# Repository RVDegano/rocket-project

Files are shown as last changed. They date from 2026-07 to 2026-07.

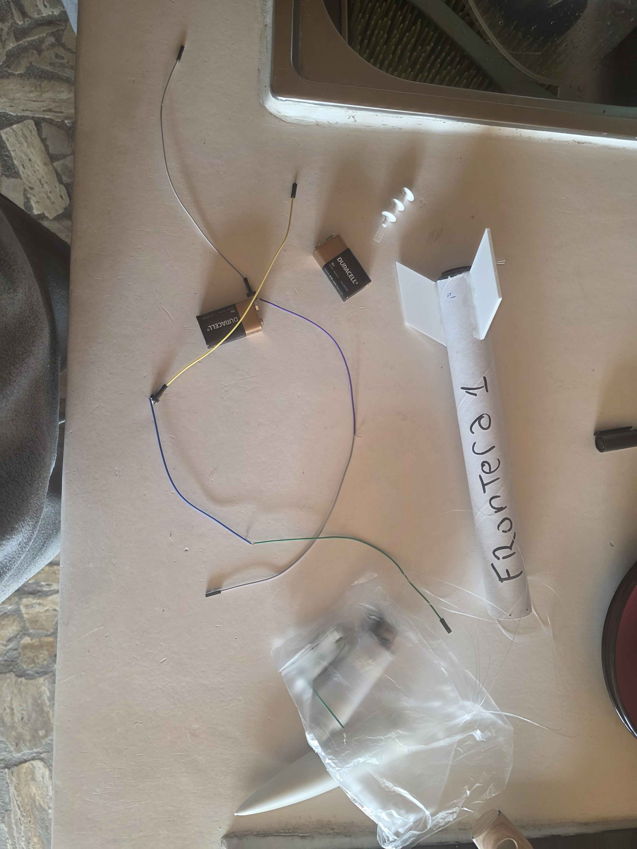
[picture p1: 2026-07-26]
DOCS/ARMADO FINAL.jpg

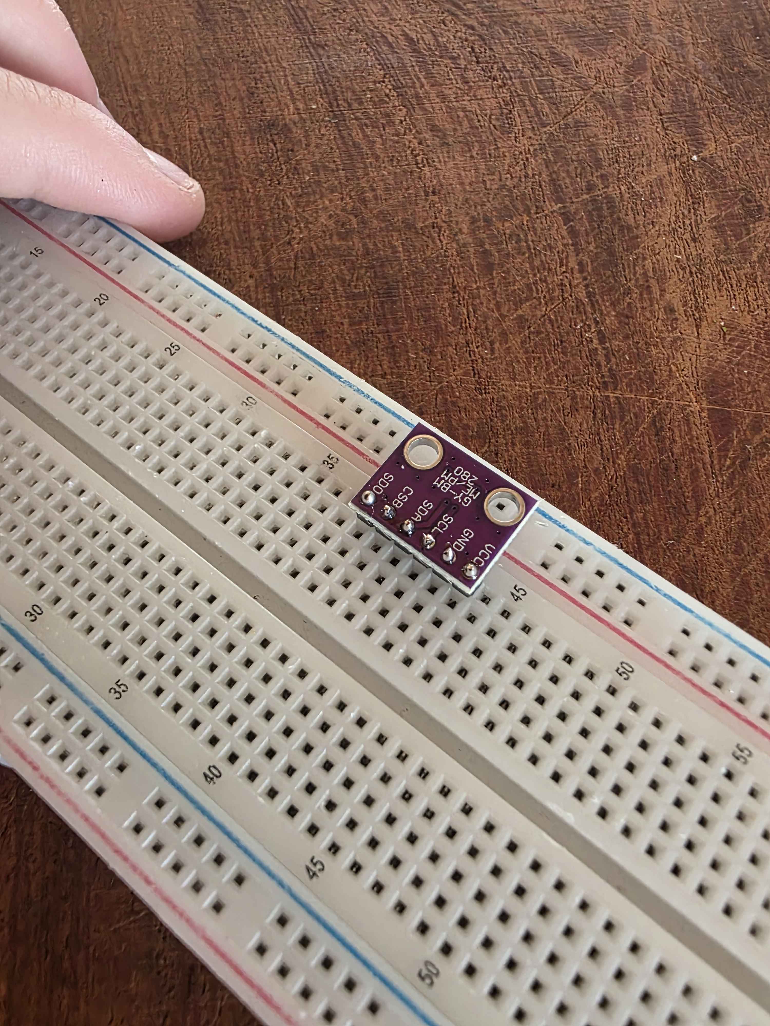
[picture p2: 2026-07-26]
DOCS/COMPONENTE.jpg

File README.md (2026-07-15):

# 🚀 Frontera 1 — D12-5 Flight Computer

A single-stage model rocket designed, simulated, and built from scratch. Includes a custom flight computer for onboard data logging during flight.

## 📋 Project Overview

| Parameter | Value |
|---|---|
| Motor | Estes D12-5 |
| Length | 42.5 cm |
| Max Diameter | 33 mm (body tube, external) |
| Mass (no motor) | 175 g |
| Mass (with motor) | 218 g |
| Stability Margin | 1.51 cal |

## 📊 Simulation Results (OpenRocket)

| Metric | Value |
|---|---|
| Apogee | 204 m |
| Max Velocity | 61.1 m/s (Mach 0.180) |
| Max Acceleration | 129 m/s² |
| CG | 24.2 cm |
| CP | 29.3 cm |

*Note: the design went through an earlier iteration with a heavier body tube that dropped stability to 1.15 cal and apogee to 180 m. This was corrected by adding a mass component near the nose, restoring the margin to 1.51 cal.*

## 🔧 Flight Computer

**Hardware:**
- Arduino Nano V3.0 (ATmega328)
- BMP280 — barometric altimeter (altitude + pressure + temperature)
- MPU6050 — IMU (acceleration + gyroscope, 6-axis)
- microSD module + card — onboard data storage

**Features:**
- Continuous data logging from power-on (20 Hz sampling rate)
- CSV output: timestamp, altitude, temperature, acceleration (x/y/z), gyroscope (x/y/z)
- No liftoff/apogee detection — logging starts as soon as the board is powered, before the rocket is loaded on the launch rail

**Recovery / ejection:**
Parachute deployment is **mechanical**, not electronically triggered. The D12-5 motor's built-in ejection charge (5-second delay after burnout) pushes the nose cone off by friction, releasing the parachute. The flight computer only logs data — it does not control ejection.

## 🖨️ Structure

| Component | Material |
|---|---|
| Body tube | Cardboard, 31.5 mm internal / 33 mm external diameter (0.75 mm wall) |
| Nose cone (ojiva) | PVC, 13 cm long, 1 mm wall |
| Fins | PETG, 3D printed, trapezoidal |

PETG was selected for the fins for its heat resistance near the motor mount / ejection charge area.

## 📁 Repository Structure

```
rocket-project/
├── simulation/        # OpenRocket files (.ork)
├── firmware/           # Arduino Nano code
├── cad/                 # 3D models (STL files, fins)
├── docs/                # Photos, flight data, analysis
└── README.md
```

## 🎯 Goals

- [x] OpenRocket simulation complete
- [x] Motor selection finalized (D12-5, chosen over Quest D16-4 for higher apogee — D16-4 reserved for a future test flight)
- [x] Flight computer designed
- [ ] Fins printed and assembled
- [ ] Full assembly
- [ ] Launch — school showcase, San Bonifacio, October 2026 (launch site: Finca Cinco Cumbres, Mendoza)
- [ ] Post-launch data analysis

## 📸 Build Process

Photos coming as construction progresses.

## 🛠️ Tools & Software

- OpenRocket — flight simulation
- Arduino IDE — firmware
- Tinkercad — 3D modeling (fins)

## 👤 Author

**Rocco V. Degano**
Electronics technician student — Instituto Tecnológico San Bonifacio, Lomas de Zamora
Interested in aerospace propulsion and flight systems.
Part of a personal aerospace engineering portfolio.

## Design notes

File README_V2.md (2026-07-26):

# 🚀 Frontera 1 — D12-5 Flight Computer

A single-stage model rocket designed, simulated, and built from scratch. Includes a custom flight computer for onboard data logging during flight. First launch completed successfully at Finca Cinco Cumbres, Uspallata, Mendoza (Argentina).

## 📋 Project Overview

| Parameter | Value |
|---|---|
| Motor | Estes D12-5 |
| Length | 42.5 cm |
| Max Diameter | 33 mm (body tube, external) |
| Mass (no motor) | 175 g |
| Mass (with motor) | 218 g |
| Stability Margin | 1.51 cal |

## 📊 Simulation vs. Real Flight Data

| Metric | Simulated (OpenRocket) | Real (first launch) |
|---|---|---|
| Apogee | 204 m | **178 m** |
| Max Acceleration | ~129 m/s² (sim, peak) | **61 m/s²** (measured) |
| Max Velocity | 61.1 m/s | — |
| Flight Duration | ~30-40 s (estimated) | **50 s** |
| Temperature | — | 11°C |

The real apogee came in below simulation, which is expected — real-world drag, wind, and the exact mass with all electronics loaded are hard to match perfectly in simulation. The overall flight profile (ignition, ascent, ejection timing) matched expectations well.

**Caveat on data reliability:** during ejection, the parachute burned and the payload (electronics bay) detached from the shock cord, getting ejected along with the nose cone instead of staying tethered as designed. Because of this, the exact accuracy of the logged flight parameters above is uncertain — the payload likely experienced additional uncontrolled forces/impacts after separating that weren't part of the intended flight profile. The numbers are presented as the best available real data, not as fully validated measurements.

*Design note: the project went through an earlier iteration with a heavier body tube that dropped stability to 1.15 cal and apogee to 180 m (simulated). This was corrected by adding a mass component near the nose, restoring the margin to 1.51 cal before the tube was later shortened to 27 cm in the final build.*

## 🔧 Flight Computer

**Hardware:**
- Arduino Nano V3.0 (ATmega328)
- BMP280 — barometric altimeter (altitude + pressure + temperature)
- MPU6050 — IMU (acceleration + gyroscope, 6-axis), read directly via I2C registers (no library) for better compatibility with clone modules
- 3x AA-equivalent battery pack (~4.1V), soldered direct to the 5V pin

**Data logging — plan change:**
The original design used a microSD module for full 20Hz CSV logging. During pre-launch testing the SD module failed (confirmed via low-level diagnostics: card responds electrically but the module could not complete initialization) and could not be replaced in time given the remote launch location (Uspallata, Mendoza).

As a fallback, the flight computer was reprogrammed to log a **flight summary to the Arduino's internal EEPROM** instead of a full time-series CSV: apogee, max acceleration magnitude, max angular velocity, average temperature, and flight duration. This was validated on the bench before launch and worked correctly during the actual flight.

A future revision will fix the SD module (or replace it) to recover full 20Hz time-series data again.

**Recovery / ejection:**
Parachute deployment is **mechanical**, not electronically triggered. The D12-5 motor's built-in ejection charge (5-second delay after burnout) pushes the nose cone off by friction, releasing the parachute. The flight computer only logs data — it does not control ejection.

## 🖨️ Structure

| Component | Material |
|---|---|
| Body tube | Cardboard, 27 cm long, 31.5 mm internal / 33 mm external diameter (0.75 mm wall) |
| Nose cone (ojiva) | PVC, 13 cm long, 1 mm wall |
| Fins | PETG, 3D printed, trapezoidal, 39.8° sweep angle |

PETG was selected for the fins for its heat resistance near the motor mount / ejection charge area.

## 🪂 First Launch Results (Uspallata, Mendoza)

- ✅ Ignition and ascent: successful
- ✅ Ejection charge and nose cone separation: successful
- ⚠️ Parachute: burned during ejection
- ⚠️ Payload (electronics bay) detached from the shock cord during ejection and was launched out along with the nose cone, instead of staying tethered as designed — all hardware was still recovered intact, but this means the logged data may include forces from an uncontrolled post-separation event, not just the intended flight profile
- ✅ Flight computer: correctly logged apogee, acceleration, temperature, and duration to EEPROM through the whole flight (see data reliability caveat above)

**Lessons for next revision:**
- Fix or replace the SD module to recover full time-series telemetry (not just a flight summary)
- Redesign parachute packing/shielding to prevent heat damage during ejection
- Redesign the payload attachment to the shock cord so it cannot detach under the force of ejection
- Consider soldering sensor connections more robustly (I2C jumpers survived bench testing but this should be hardened further for repeated flights)

## 📁 Repository Structure

```
rocket-project/
├── simulation/        # OpenRocket files (.ork)
├── firmware/           # Arduino Nano code (main + EEPROM reader)
├── cad/                 # 3D models (STL files, fins)
├── docs/                # Photos, flight data, analysis
└── README.md
```

## 🎯 Goals

- [x] OpenRocket simulation complete
- [x] Motor selection finalized (D12-5, chosen over Quest D16-4 for higher apogee — D16-4 reserved for a future test flight)
- [x] Flight computer designed and built (with EEPROM fallback logging)
- [x] Fins printed and assembled
- [x] Full assembly
- [x] Launch — school showcase, San Bonifacio, October 2026 (launch site: Finca Cinco Cumbres, Mendoza)
- [x] Post-launch data analysis
- [ ] V2: active control (TVC or moving fins), full SD telemetry restored

## 🛠️ Tools & Software

- OpenRocket — flight simulation
- Arduino IDE — firmware
- Tinkercad — 3D modeling (fins)

## 👤 Author

**Rocco V. Degano**
Electronics technician student — Instituto Tecnológico San Bonifacio, Lomas de Zamora
Interested in aerospace propulsion and flight systems.
Part of a personal aerospace engineering portfolio.

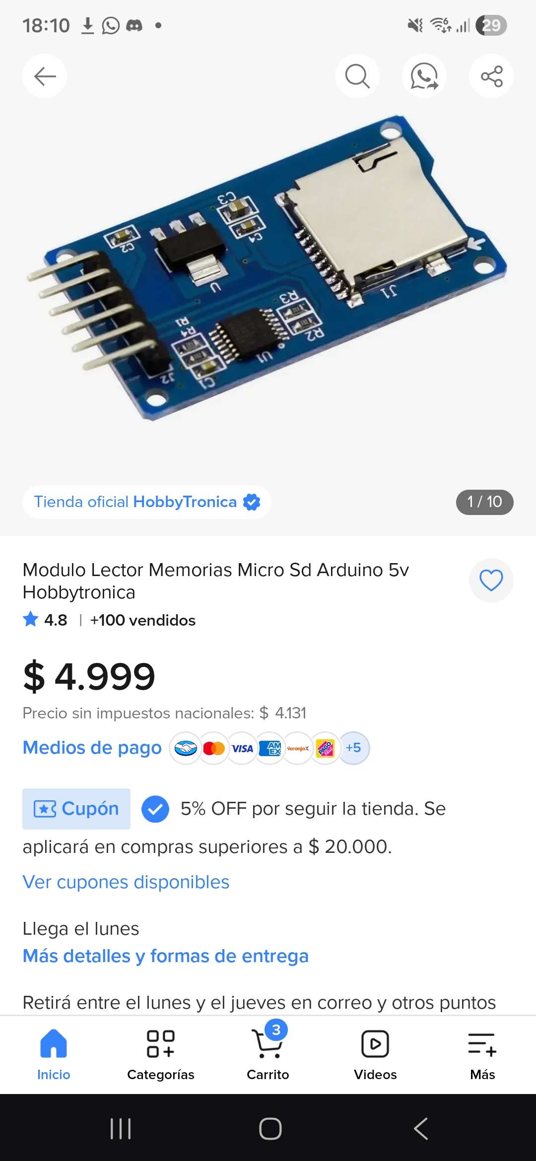
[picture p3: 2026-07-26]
DOCS/LECTORMICROSD.jpg

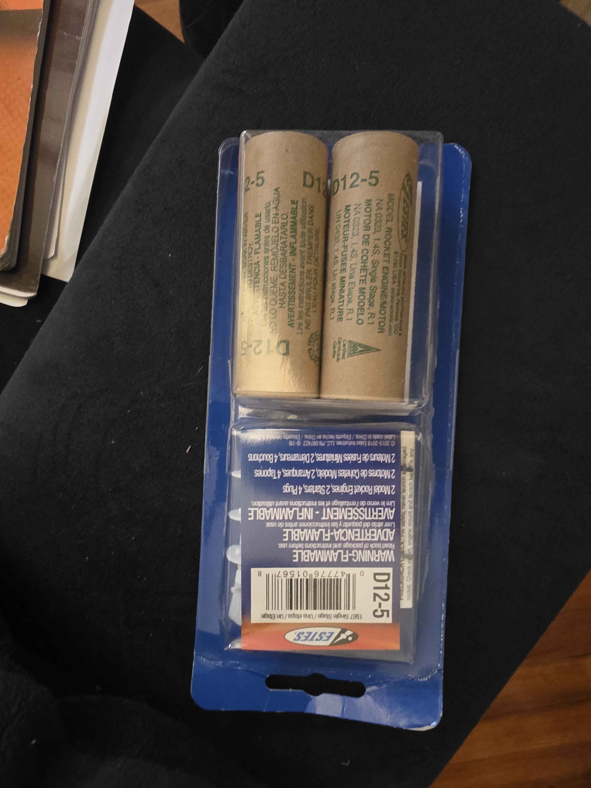
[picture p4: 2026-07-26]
DOCS/MOTOR.jpg

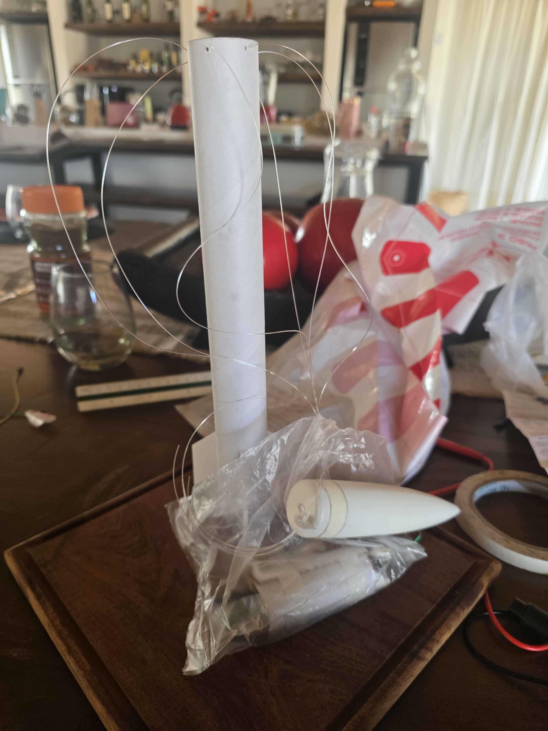
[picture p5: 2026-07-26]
DOCS/PARACHUTE.jpg

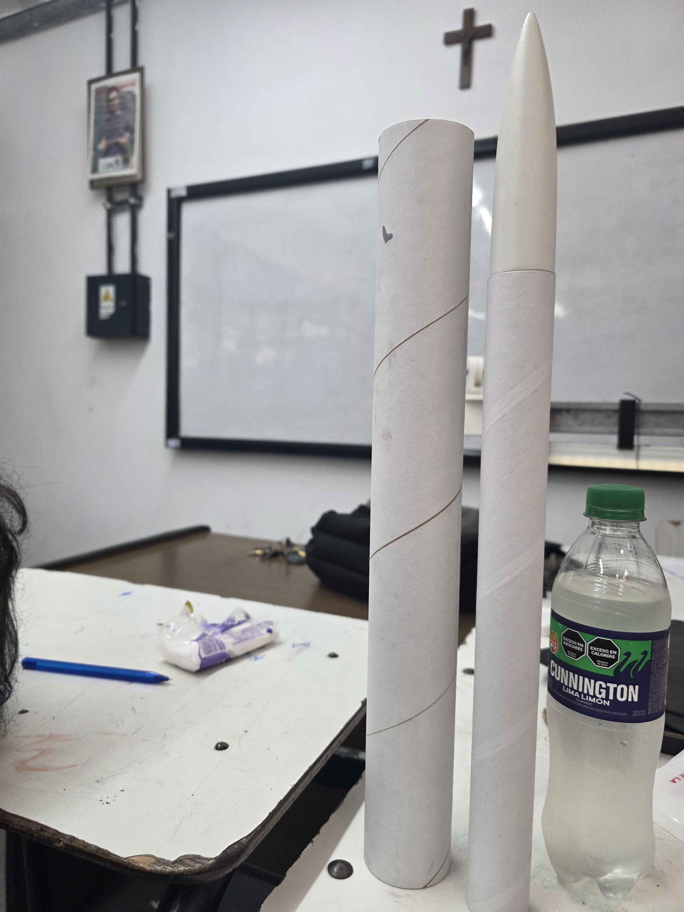
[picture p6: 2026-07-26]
DOCS/CUERPO Y OJIVA 1dia.jpg

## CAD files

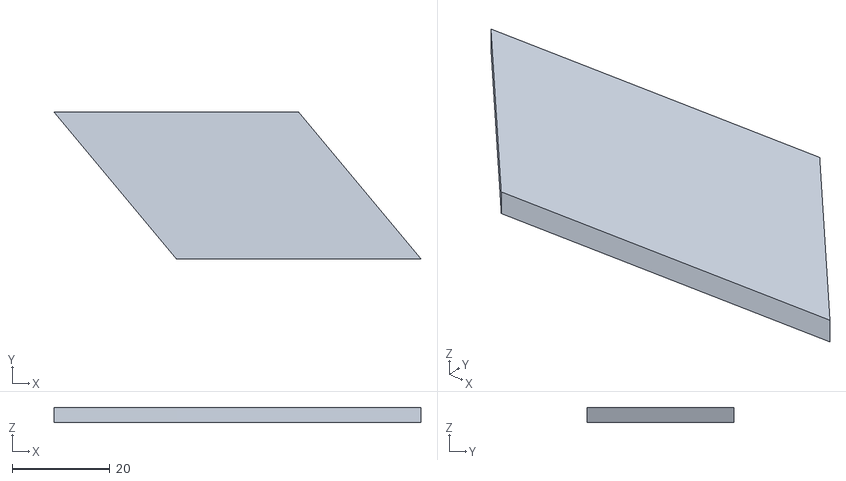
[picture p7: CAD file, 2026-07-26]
CAD/ALETAS COHETE Frontera 1 stl.stl
75.0 x 30.0 x 3.00

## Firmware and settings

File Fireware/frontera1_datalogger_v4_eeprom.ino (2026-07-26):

/*
  ============================================================
  FRONTERA 1 - Data Logger de vuelo (v4 - respaldo EEPROM, sin SD)
  ============================================================
  Plan B: como el modulo SD no funciona, este sketch guarda un
  RESUMEN del vuelo en la EEPROM interna del Arduino Nano (1KB),
  en vez del log completo a 20Hz.

  Que guarda (resumen, no serie temporal completa):
    - Apogeo (altitud maxima alcanzada)
    - Aceleracion maxima (magnitud del vector accel)
    - Duracion total del vuelo detectado
    - Temperatura promedio
    - Orientacion (gyro) maxima detectada

  Como funciona:
    - Arranca a loguear en RAM apenas se prende (como el original)
    - Cada muestra actualiza los maximos/minimos en RAM
    - Cada 2 segundos, graba el resumen actual a EEPROM
      (asi si se corta la alimentacion en cualquier momento,
      lo ultimo grabado sigue en la EEPROM)
    - Para LEER los datos despues del vuelo: subir el sketch
      "eeprom_reader.ino" (lo armamos aparte) que solo lee e
      imprime los valores guardados, sin necesidad de tocar
      el sketch de vuelo

  Conexiones (sin cambios, SD ya no se usa):
    BMP280  SDA -> A4      SCL -> A5
    MPU6050 SDA -> A4      SCL -> A5   (mismo bus I2C)
    Todos VCC -> 5V, todos GND -> GND
  ============================================================
*/

#include <Wire.h>
#include <EEPROM.h>
#include <Adafruit_Sensor.h>
#include <Adafruit_BMP280.h>

const unsigned long SAMPLE_INTERVAL_MS = 50;   // 20 Hz
const unsigned long EEPROM_SAVE_INTERVAL_MS = 2000; // graba a EEPROM cada 2s
const int LED_PIN = LED_BUILTIN;

// Direccion base en EEPROM donde se guarda el resumen
const int EEPROM_ADDR = 0;

// ---------- MPU6050 (registros, sin libreria) ----------
uint8_t mpuAddr = 0x68;
#define MPU_PWR_MGMT_1   0x6B
#define MPU_ACCEL_CONFIG 0x1C
#define MPU_GYRO_CONFIG  0x1B
#define MPU_ACCEL_XOUT_H 0x3B
const float ACCEL_SCALE = 2048.0;
const float GYRO_SCALE  = 65.5;
const float GRAVITY     = 9.80665;
const float GYRO_DEG_TO_RAD = 0.0174533;

Adafruit_BMP280 bmp;

bool bmpOk = false;
bool mpuOk = false;

float seaLevelPressure = 1013.25;

unsigned long lastSampleTime = 0;
unsigned long lastEepromSave = 0;
unsigned long startTime = 0;

// ---------- Estructura del resumen guardado en EEPROM ----------
struct FlightSummary {
  uint32_t magicNumber;     // para verificar que la EEPROM tiene datos validos
  float maxAltitude;
  float maxAccelMagnitude;
  float maxGyroMagnitude;
  float avgTemperature;
  unsigned long flightDurationMs;
  uint32_t sampleCount;
};

FlightSummary summary;
float tempSum = 0;

const uint32_t MAGIC_NUMBER = 0xF12A2026; // "Frontera 1, 2026" como marca

// ---------- Funciones auxiliares MPU6050 ----------
bool mpuWriteReg(uint8_t addr, uint8_t reg, uint8_t value) {
  Wire.beginTransmission(addr);
  Wire.write(reg);
  Wire.write(value);
  return (Wire.endTransmission() == 0);
}

bool mpuProbe(uint8_t addr) {
  Wire.beginTransmission(addr);
  return (Wire.endTransmission() == 0);
}

bool mpuInit() {
  if (mpuProbe(0x68)) {
    mpuAddr = 0x68;
  } else if (mpuProbe(0x69)) {
    mpuAddr = 0x69;
  } else {
    return false;
  }
  if (!mpuWriteReg(mpuAddr, MPU_PWR_MGMT_1, 0x00)) return false;
  delay(50);
  mpuWriteReg(mpuAddr, MPU_ACCEL_CONFIG, 0x18);
  mpuWriteReg(mpuAddr, MPU_GYRO_CONFIG, 0x08);
  return true;
}

bool mpuRead(float &ax, float &ay, float &az, float &gx, float &gy, float &gz) {
  Wire.beginTransmission(mpuAddr);
  Wire.write(MPU_ACCEL_XOUT_H);
  if (Wire.endTransmission(false) != 0) return false;
  uint8_t bytesReceived = Wire.requestFrom(mpuAddr, (uint8_t)14);
  if (bytesReceived < 14) return false;
  int16_t rawAx = (Wire.read() << 8) | Wire.read();
  int16_t rawAy = (Wire.read() << 8) | Wire.read();
  int16_t rawAz = (Wire.read() << 8) | Wire.read();
  Wire.read(); Wire.read();
  int16_t rawGx = (Wire.read() << 8) | Wire.read();
  int16_t rawGy = (Wire.read() << 8) | Wire.read();
  int16_t rawGz = (Wire.read() << 8) | Wire.read();
  ax = (rawAx / ACCEL_SCALE) * GRAVITY;
  ay = (rawAy / ACCEL_SCALE) * GRAVITY;
  az = (rawAz / ACCEL_SCALE) * GRAVITY;
  gx = (rawGx / GYRO_SCALE) * GYRO_DEG_TO_RAD;
  gy = (rawGy / GYRO_SCALE) * GYRO_DEG_TO_RAD;
  gz = (rawGz / GYRO_SCALE) * GYRO_DEG_TO_RAD;
  return true;
}

void saveSummaryToEeprom() {
  EEPROM.put(EEPROM_ADDR, summary);
}

void setup() {
  Serial.begin(115200);
  pinMode(LED_PIN, OUTPUT);

  Serial.println(F("=== FRONTERA 1 - Data Logger v4 (EEPROM, sin SD) ==="));

  Wire.begin();

  Serial.print(F("Iniciando BMP280... "));
  if (bmp.begin(0x76) || bmp.begin(0x77)) {
    bmpOk = true;
    bmp.setSampling(Adafruit_BMP280::MODE_NORMAL,
                     Adafruit_BMP280::SAMPLING_X2,
                     Adafruit_BMP280::SAMPLING_X16,
                     Adafruit_BMP280::FILTER_X16,
                     Adafruit_BMP280::STANDBY_MS_1);
    Serial.println(F("OK"));
  } else {
    Serial.println(F("FALLO - revisar conexion I2C"));
  }

  Serial.print(F("Iniciando MPU6050... "));
  if (mpuInit()) {
    mpuOk = true;
    Serial.print(F("OK (direccion 0x"));
    Serial.print(mpuAddr, HEX);
    Serial.println(F(")"));
  } else {
    Serial.println(F("FALLO - revisar conexion I2C"));
  }

  if (bmpOk) {
    delay(500);
    seaLevelPressure = bmp.readPressure() / 100.0F;
    Serial.print(F("Presion de referencia (suelo): "));
    Serial.print(seaLevelPressure);
    Serial.println(F(" hPa"));
  }

  // --- Inicializar resumen en RAM ---
  summary.magicNumber = MAGIC_NUMBER;
  summary.maxAltitude = -1000;
  summary.maxAccelMagnitude = 0;
  summary.maxGyroMagnitude = 0;
  summary.avgTemperature = 0;
  summary.flightDurationMs = 0;
  summary.sampleCount = 0;
  tempSum = 0;

  if (!bmpOk && !mpuOk) {
    Serial.println(F("ADVERTENCIA: ningun sensor disponible."));
    for (int i = 0; i < 10; i++) {
      digitalWrite(LED_PIN, HIGH);
      delay(100);
      digitalWrite(LED_PIN, LOW);
      delay(100);
    }
  } else {
    Serial.println(F("Todo OK. Iniciando logging a EEPROM (resumen)..."));
    digitalWrite(LED_PIN, HIGH);
  }

  startTime = millis();
  lastSampleTime = startTime;
  lastEepromSave = startTime;
}

void loop() {
  unsigned long now = millis();

  if (now - lastSampleTime >= SAMPLE_INTERVAL_MS) {
    lastSampleTime = now;
    processSample(now - startTime);
  }

  // Grabar a EEPROM periodicamente (no en cada muestra, para no
  // desgastar la EEPROM: tiene vida util limitada de ~100,000 escrituras)
  if (now - lastEepromSave >= EEPROM_SAVE_INTERVAL_MS) {
    lastEepromSave = now;
    saveSummaryToEeprom();
  }
}

void processSample(unsigned long elapsedMs) {
  float altitude = NAN, temperature = NAN;
  float ax = NAN, ay = NAN, az = NAN, gx = NAN, gy = NAN, gz = NAN;

  if (bmpOk) {
    temperature = bmp.readTemperature();
    float pressure = bmp.readPressure() / 100.0F;
    altitude = 44330.0 * (1.0 - pow(pressure / seaLevelPressure, 0.1903));
  }

  if (mpuOk) {
    mpuRead(ax, ay, az, gx, gy, gz);
  }

  // --- Actualizar maximos/resumen ---
  if (bmpOk) {
    if (altitude > summary.maxAltitude) summary.maxAltitude = altitude;
    tempSum += temperature;
  }

  if (mpuOk) {
    float accelMag = sqrt(ax * ax + ay * ay + az * az);
    float gyroMag = sqrt(gx * gx + gy * gy + gz * gz);
    if (accelMag > summary.maxAccelMagnitude) summary.maxAccelMagnitude = accelMag;
    if (gyroMag > summary.maxGyroMagnitude) summary.maxGyroMagnitude = gyroMag;
  }

  summary.sampleCount++;
  summary.flightDurationMs = elapsedMs;
  if (summary.sampleCount > 0) {
    summary.avgTemperature = tempSum / summary.sampleCount;
  }

  // --- Debug por Serial (para ver en vivo mientras esta conectado por USB) ---
  Serial.print(F("t="));
  Serial.print(elapsedMs);
  Serial.print(F("ms alt="));
  Serial.print(altitude, 2);
  Serial.print(F("m accel="));
  Serial.print(sqrt(ax * ax + ay * ay + az * az), 2);
  Serial.println(F("m/s2"));
}

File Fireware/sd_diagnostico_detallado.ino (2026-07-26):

/*
  Diagnostico SD detallado (bajo nivel) - v2 simplificado
  Usa Sd2Card directamente para obtener informacion mas especifica
  sobre por que falla la inicializacion. Sin SdVolume (no disponible
  en todas las versiones de la libreria SD).
*/

#include <SPI.h>
#include <SD.h>
#include <utility/Sd2Card.h>

const int SD_CS_PIN = 10;

Sd2Card card;

void setup() {
  Serial.begin(115200);
  while (!Serial) { delay(10); }
  delay(1000);

  Serial.println(F("=== Diagnostico SD detallado ==="));

  pinMode(SD_CS_PIN, OUTPUT);
  digitalWrite(SD_CS_PIN, HIGH);

  Serial.println(F("Inicializando tarjeta (SPI_HALF_SPEED)..."));
  if (!card.init(SPI_HALF_SPEED, SD_CS_PIN)) {
    Serial.println(F("FALLO en card.init()"));
    Serial.println(F("Esto es un error a nivel MUY bajo. Causas tipicas:"));
    Serial.println(F("1. Conexion fisica (revisar continuidad de cada cable)"));
    Serial.println(F("2. Modulo SD danado"));
    Serial.println(F("3. Alimentacion insuficiente (probar con 3.3V en vez de 5V)"));
    Serial.println(F("4. Tarjeta danada/incompatible"));
    return;
  }
  Serial.println(F("card.init() OK - la tarjeta responde electricamente."));

  Serial.print(F("Tipo de tarjeta: "));
  switch (card.type()) {
    case SD_CARD_TYPE_SD1:
      Serial.println(F("SD1"));
      break;
    case SD_CARD_TYPE_SD2:
      Serial.println(F("SD2"));
      break;
    case SD_CARD_TYPE_SDHC:
      Serial.println(F("SDHC"));
      break;
    default:
      Serial.println(F("Desconocido"));
  }

  Serial.println(F("Ahora probando SD.begin() (capa alta, con sistema de archivos)..."));
  if (!SD.begin(SD_CS_PIN, SPI_HALF_SPEED)) {
    Serial.println(F("SD.begin() FALLO."));
    Serial.println(F("La tarjeta responde a nivel electrico (card.init() OK arriba),"));
    Serial.println(F("pero el sistema de archivos no es FAT16/FAT32 valido."));
    Serial.println(F("-> Hace falta formatearla en FAT32."));
  } else {
    Serial.println(F("SD.begin() OK. Todo funcionando."));
  }
}

void loop() {
}
